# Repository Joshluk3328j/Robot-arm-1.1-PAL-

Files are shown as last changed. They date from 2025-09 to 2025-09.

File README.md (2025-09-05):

# Robot Arm v1.1 – PAL

Welcome to the second iteration of the **6 DOF Robotic Arm** project, codenamed **PAL** (Precision Articulated Limb). This version brings significant improvements over its predecessor, featuring lighter yet stronger components, enhanced torque calculations, and refined control logic. Developed during my Industrial Training at **NCAIR**, with guidance and support from **@Mac Anthony**.

🔗 **Related Links**  
- [Robot Arm v1.0](https://github.com/Joshluk3328j/robot-arm-1.0)
- [Robot Arm v1.1 PAL Repository](https://github.com/Joshluk3328j/Robot-arm-1.1-PAL-)

---

## 📂 Repository Structure

```
├── blocks/                  # Conceptual block diagrams
├── code/                    # Arduino Nano control code (servo, joystick, playback)
├── drawings/                # Technical drawings of parts
├── Gcode/                   # 3D printer G-code files
├── PRT files/               # Native CAD part files (SolidWorks/Creo)
│   ├── Base/                # Base components
│   ├── controller/          # Controller housing
│   ├── end_effector/        # Gripper/end effector parts
│   ├── Link/                # Arm linkage components
│   └── ...
├── Rendered/                # Rendered images of the design
│   ├── arm/                 # Arm renders
│   └── controller_box/      # Controller renders
├── STL files/               # 3D-printable STL models
│   ├── base/                # Base STL files
│   ├── controller_box/      # Controller housing STL files
│   ├── end_effector/        # Gripper STL files
│   └── links/               # Arm linkage STL files
└── torque_calc/             # Torque requirement calculations
```

---

## ⚙️ Features

- **6 Degrees of Freedom (DOF)**: Full range of motion for precise control.
- **Arduino Nano Control**: Powered by an Arduino Nano for reliable operation.
- **Joystick & Button Inputs**: Intuitive manual control with joysticks and buttons.
- **Motion Recording & Playback**: Store motion sequences and replay them autonomously.
- **Optimized Torque Calculations**: Ensures reliable performance under load.
- **Lightweight Design**: Uses optimized CAD parts for reduced weight and increased strength.
- **3D-Printable**: Includes STL files and G-code for easy fabrication.

---

## 🚀 Getting Started

### Hardware Requirements
- **Arduino Nano** (microcontroller)
- **6x Servo Motors** (for arm joints)
- **Joysticks** (potentiometer-based for axes control)
- **Control Buttons + Buzzer** (for user inputs and feedback)
- **3D-Printed Parts** (STL and G-code files provided in `STL files/` and `Gcode/`)

### Software Requirements
- **Arduino IDE**: For uploading control code (located in `code/`).
- **SolidWorks/Creo**: For viewing/editing CAD files (located in `PRT files/`).
- **Cura/PrusaSlicer**: For slicing STL files for 3D printing (located in `STL files/`).

### Installation
1. **Clone the Repository**:
   ```bash
   git clone https://github.com/Joshluk3328j/Robot-arm-1.1-PAL-
   ```
2. **Upload Arduino Code**:
   - Open `code/` in the Arduino IDE.
   - Connect the Arduino Nano and upload the code.
3. **3D Print Parts**:
   - Use Cura/PrusaSlicer to slice STL files in `STL files/`.
   - Print using a 3D printer or use provided G-code in `Gcode/`.
4. **Assemble Hardware**:
   - Follow technical drawings in `drawings/` for assembly.
   - Connect servo motors, joysticks, buttons, and buzzer to the Arduino Nano as per the schematics in `blocks/`.

---

## 🎮 Controls

### Joystick Controls
- **Axes**: Control **base**, **shoulder**, **elbow**, and **wrist pitch**.
- **Button Left/Right**:
  - Single press: Control **wrist roll** and **gripper**.
  - Double press: Toggle direction of wrist roll/gripper.

### Button Controls
- **Button1 (Pin 12)**:
  - **Single Press**: Save the current arm position.
  - **Double Press**: Switch between **MANUAL** and **PLAY** modes.
- **Button2 (Pin 4)**:
  - **Single Press (in PLAY mode)**: Pause or resume playback.
  - **Double Press (in MANUAL mode)**: Delete the last recorded motion.
  - **Double Press (in PLAY mode)**: Clear all saved motions.

---

## 📸 Demo

### Rendered Arm
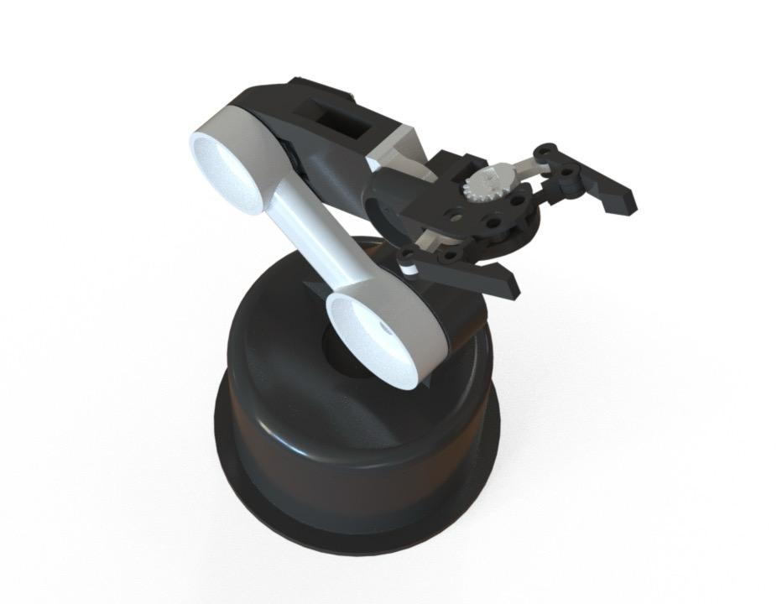
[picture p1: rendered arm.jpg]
Rendered Arm
 

### Built Arm (Real Prototype)
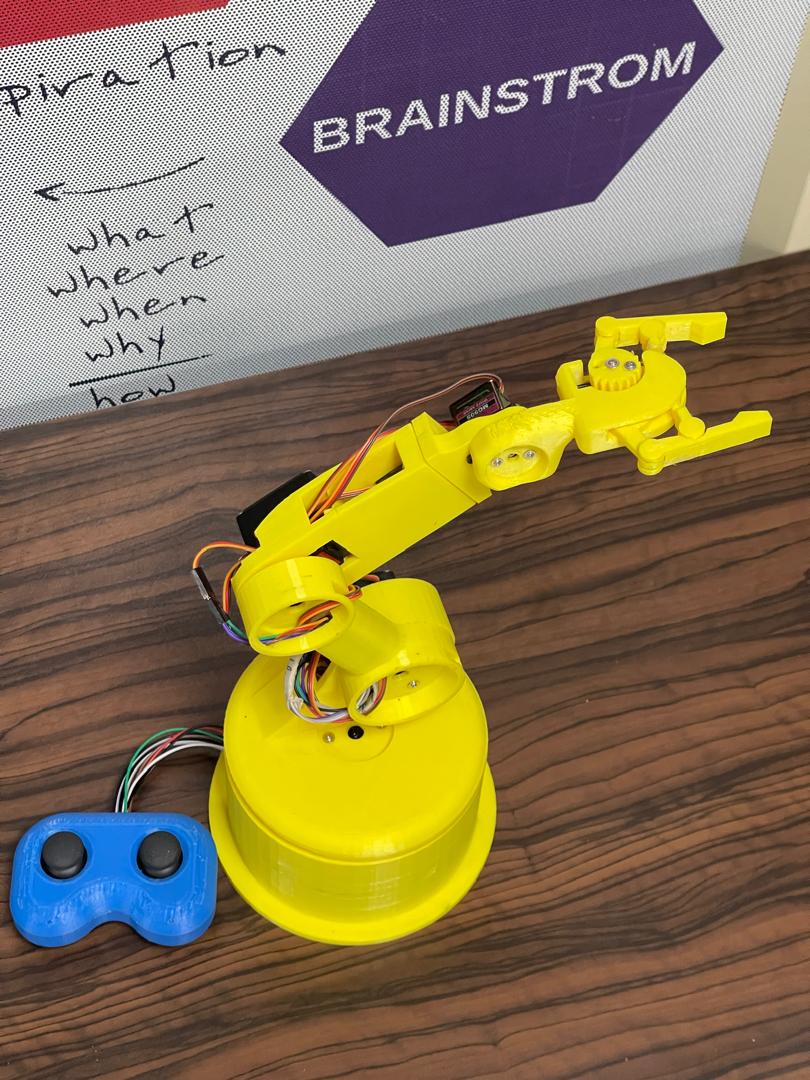
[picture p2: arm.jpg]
Built Arm


---

## 🙏 Acknowledgements

- **God**: For strength and inspiration.
- **@Mac Anthony**: For guidance and mentorship.
- **NCAIR**: For providing the opportunity and resources to develop this project.

---

## 📜 License

This project is licensed under the **MIT License**.  
Feel free to fork, modify, and enhance the project! 🚀

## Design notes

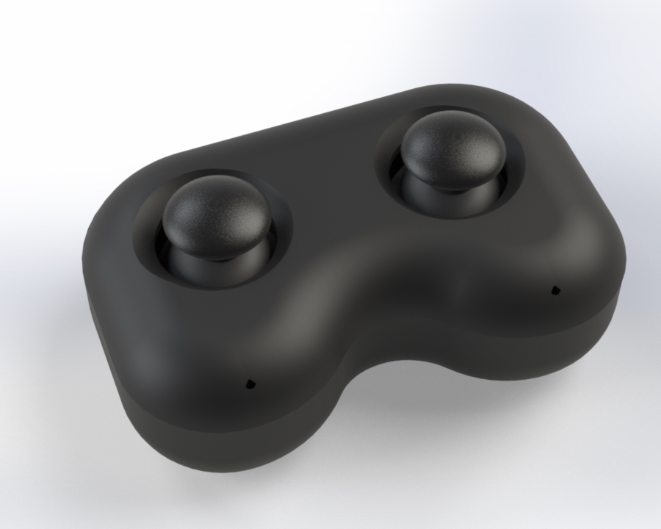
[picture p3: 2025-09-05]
Rendered/controller_box/controller_box.jpg

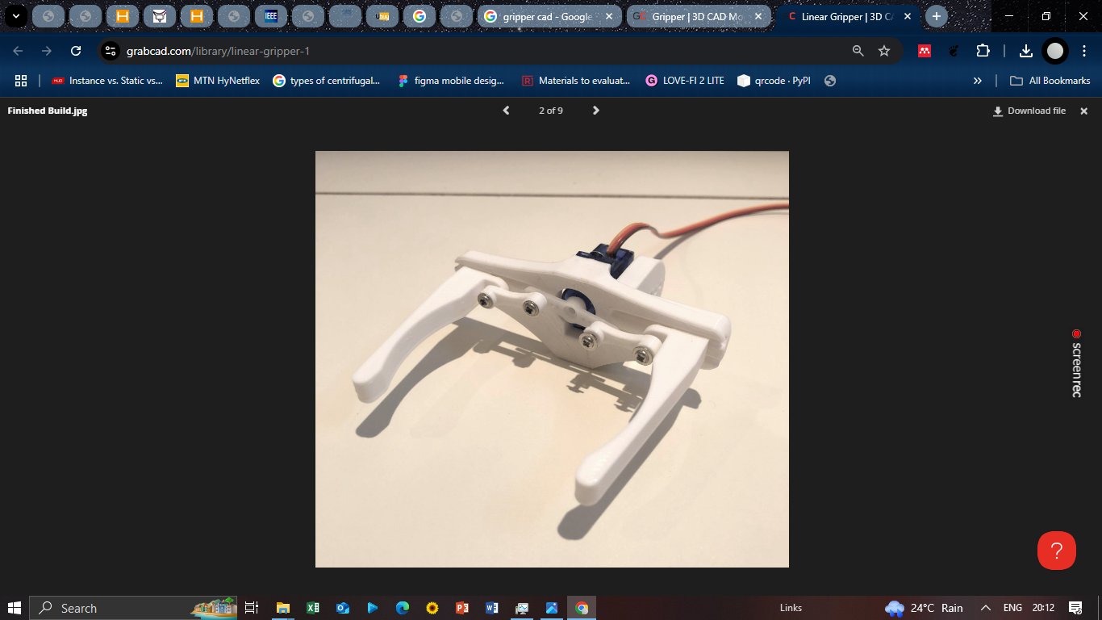
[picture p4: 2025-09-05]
PRT files/end_effector/Screenshot (245).png

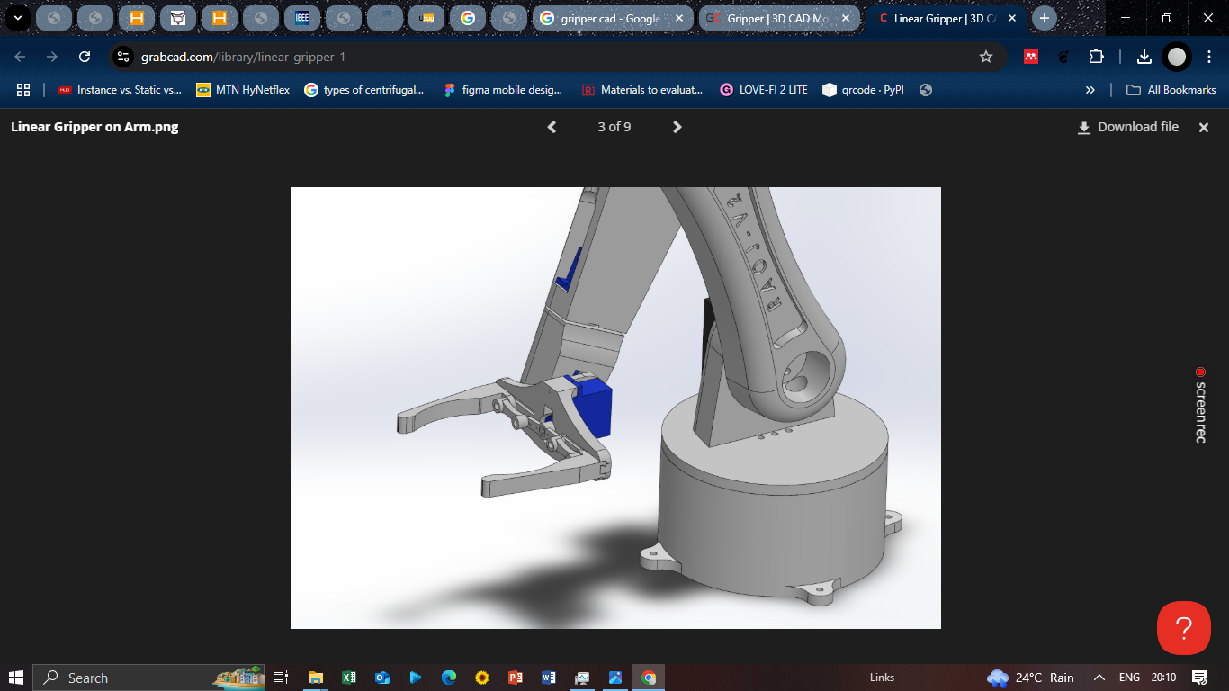
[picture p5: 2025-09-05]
PRT files/end_effector/Screenshot (244).png

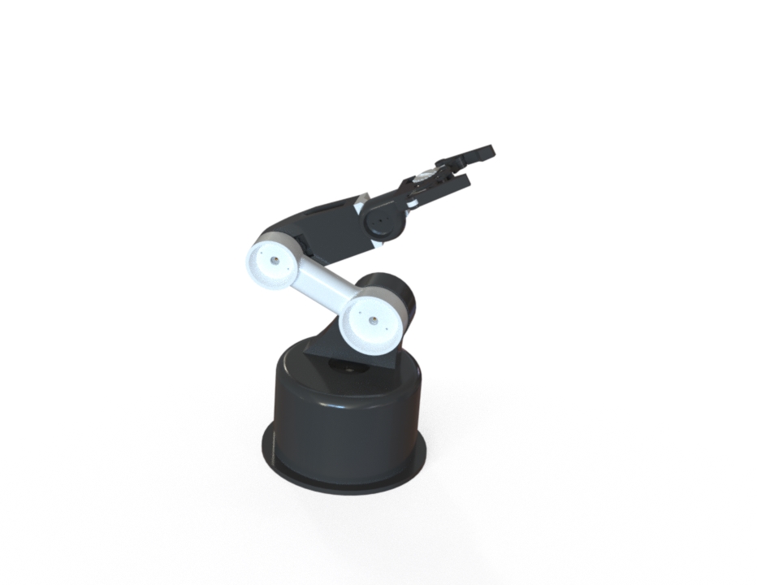
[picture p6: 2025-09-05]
Rendered/arm/arm1/arm1.jpg

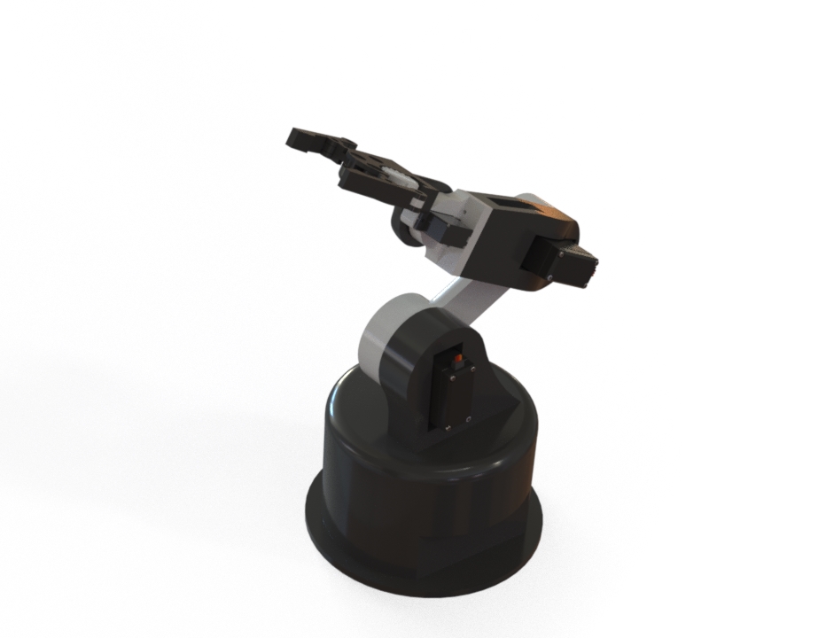
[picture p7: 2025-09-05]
Rendered/arm/arm3/arm3.jpg

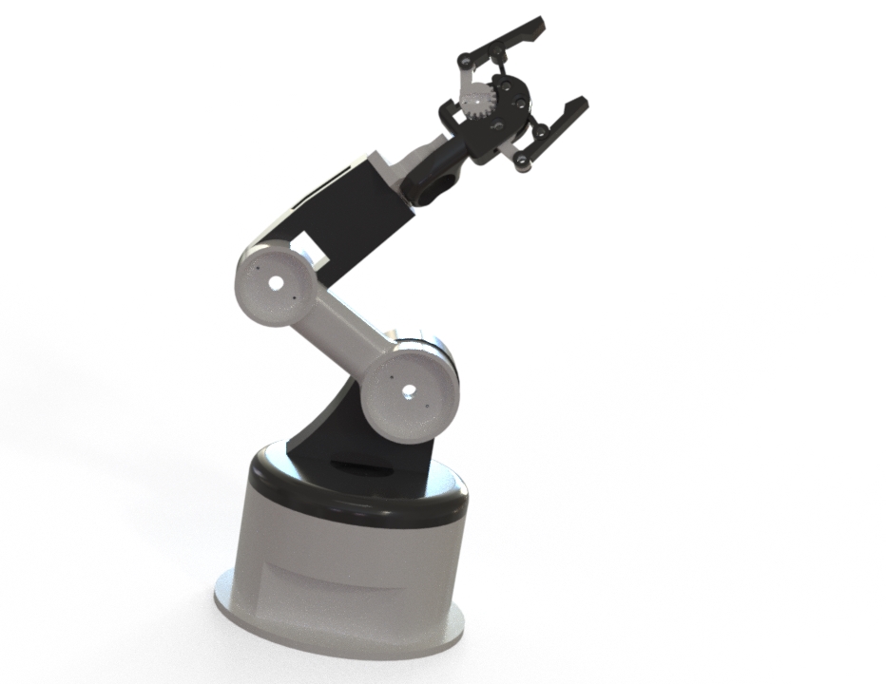
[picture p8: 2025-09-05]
Rendered/arm/arm4/arm4.jpg

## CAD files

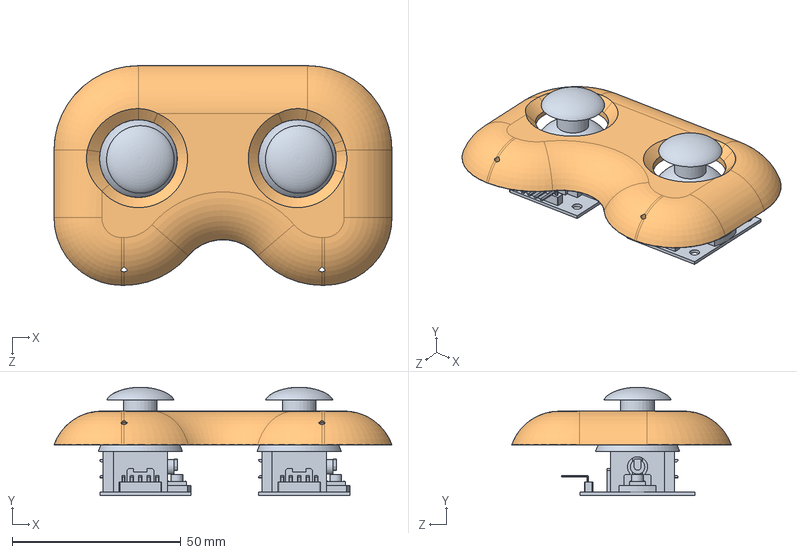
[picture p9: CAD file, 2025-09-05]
PRT files/controller/Assem1.SLDASM
100.0 x 32.0 x 65.0 mm
Controller Part2
Joystick HW504 Board x 2

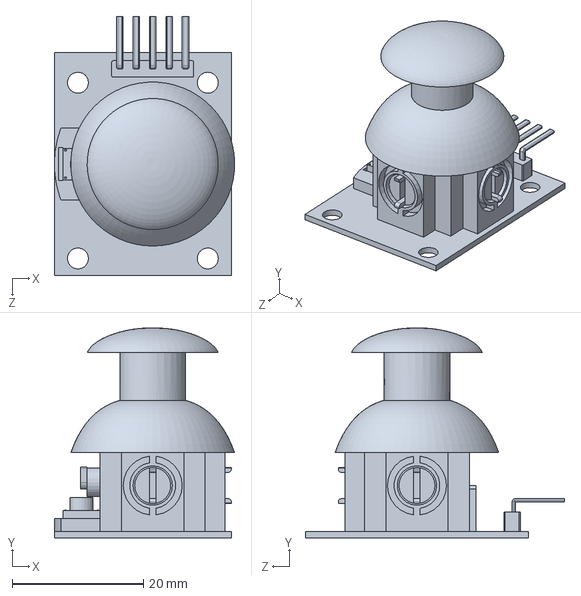
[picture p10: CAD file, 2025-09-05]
PRT files/controller/Joystick HW504 Board.SLDPRT
27.5 x 32.0 x 39.5 mm

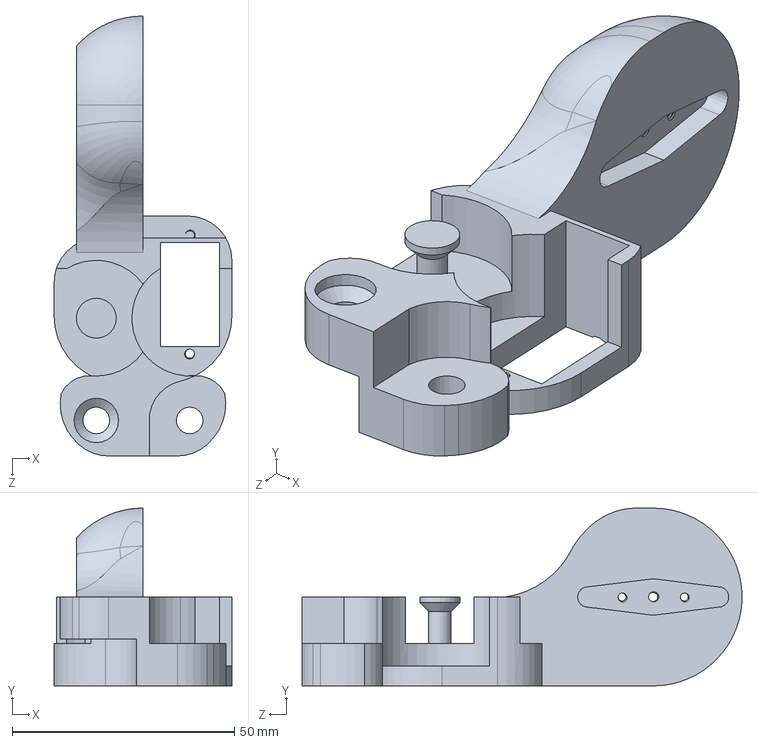
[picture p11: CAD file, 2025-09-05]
PRT files/end effector/end_effector_part1.SLDPRT
40.0 x 40.0 x 99.0 mm

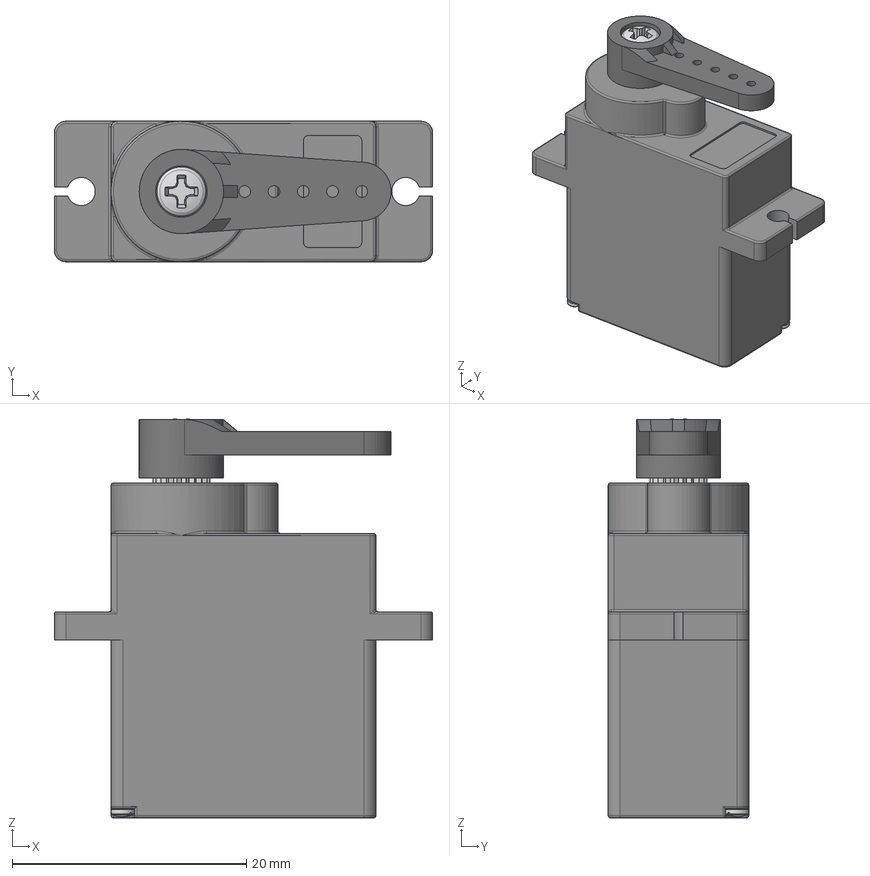
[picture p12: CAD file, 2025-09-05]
PRT files/end_effector/MG90S Micro Servo Motor.step
32.3 x 12.0 x 34.1 mm
Shaft
Horn
Screw

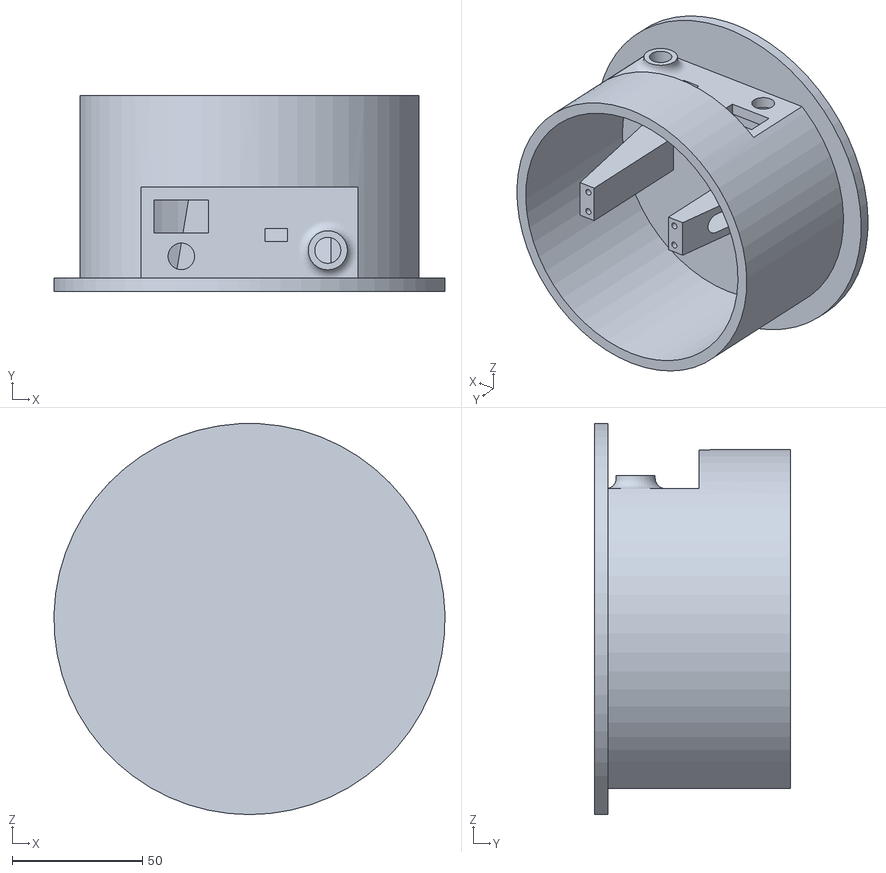
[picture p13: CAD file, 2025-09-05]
STL files/base/Base.STL
149.9 x 75.0 x 150.0

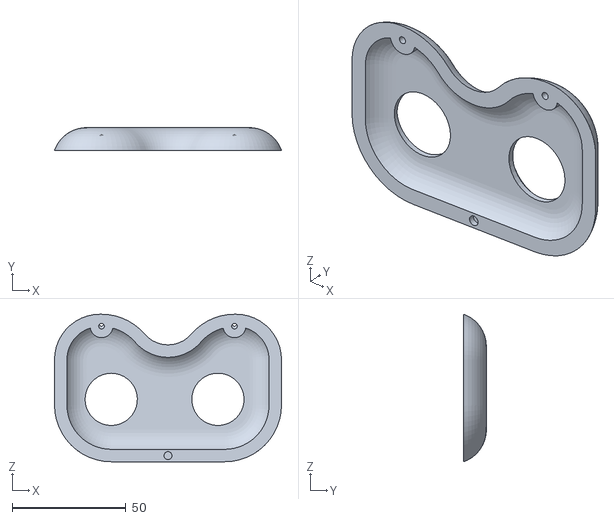
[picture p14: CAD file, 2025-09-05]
STL files/controller_box/Controller Part2.STL
100.0 x 10.00 x 65.0

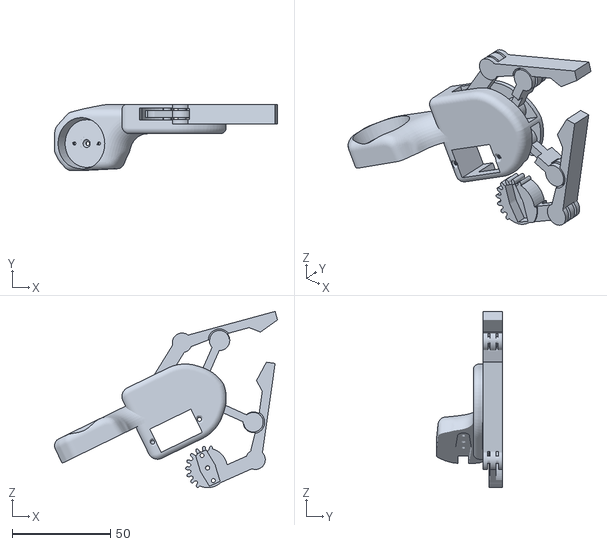
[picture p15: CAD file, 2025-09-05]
STL files/end_effector/Assem1.STL
113.7 x 33.9 x 89.9

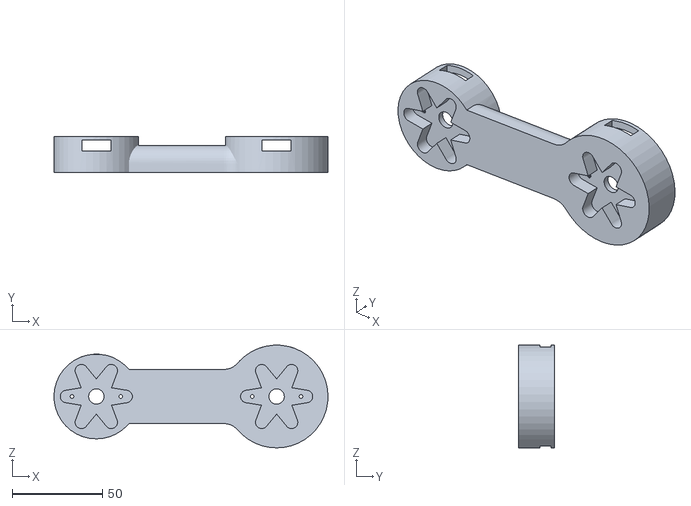
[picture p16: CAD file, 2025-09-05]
STL files/links/Link2.STL
152.0 x 20.0 x 57.0

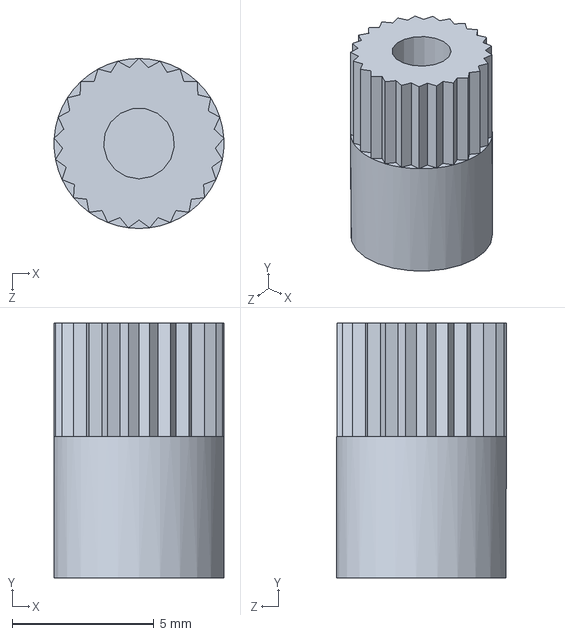
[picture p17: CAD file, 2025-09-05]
PRT files/Base/Servo MG996R Shaft.SLDPRT
5.99 x 9.00 x 6.00 mm

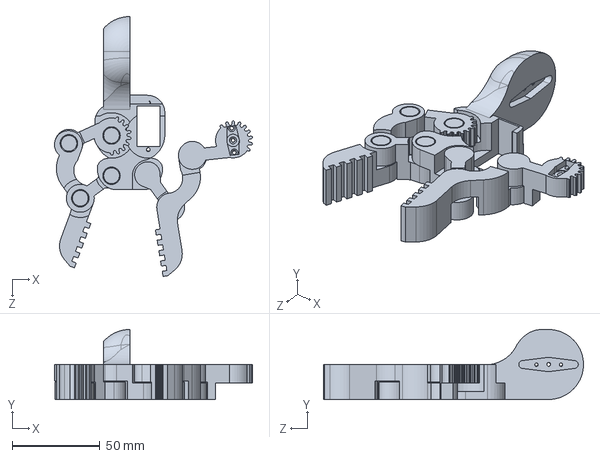
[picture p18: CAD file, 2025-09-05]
PRT files/end effector/end_effector2.SLDPRT
113.1 x 40.0 x 148.5 mm

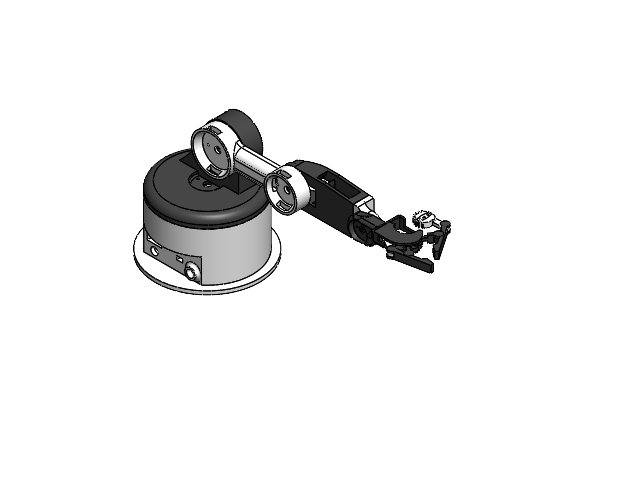
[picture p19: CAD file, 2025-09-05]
PRT files/Assembly.SLDASM
Link1
Link2
link3
link4
Base
gear
gear2
case

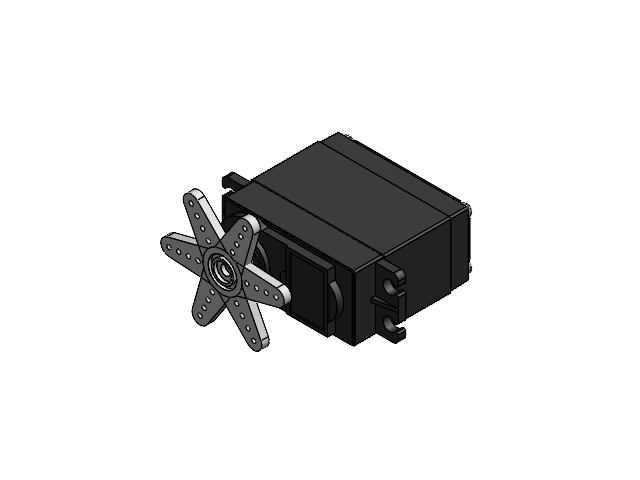
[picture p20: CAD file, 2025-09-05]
PRT files/Base/MG996R SBORKA.SLDASM
Servo MG996R
Servo MG996R Shaft
Servo MG996R arm01 x 3

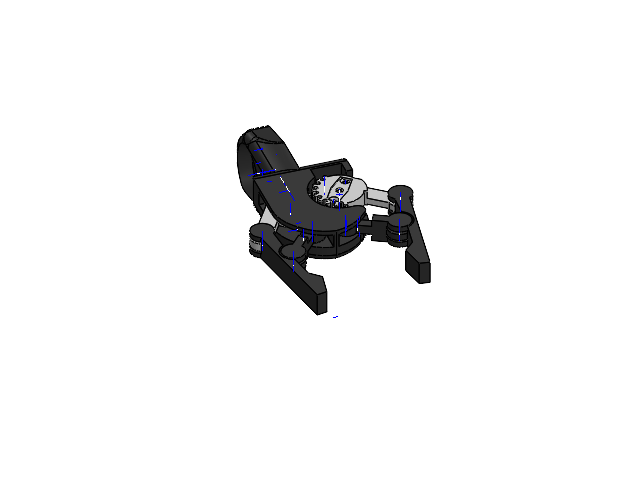
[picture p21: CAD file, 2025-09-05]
PRT files/end_effector_2/Assem1.SLDASM
gear
gear2
case

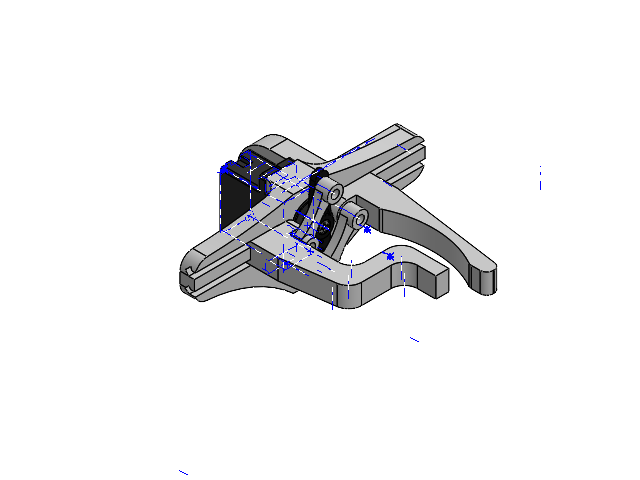
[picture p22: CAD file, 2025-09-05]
PRT files/end_effector/Linear Gripper.SLDASM
Linear Base
LGrip
Linear Link x 2
LGrip Mirror
MG90S Micro Servo Motor

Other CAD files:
PRT files/Base/base_assembly.SLDASM
PRT files/end effector/end_effector.SLDASM
PRT files/controller/Controller Part2.SLDPRT
PRT files/Base/Base.SLDPRT
PRT files/Base/Servo MG996R arm01.SLDPRT
PRT files/Base/Servo MG996R.SLDPRT
PRT files/Link/Link1.SLDPRT
PRT files/Link/Link2.SLDPRT
PRT files/Link/MG90S Micro Servo Motor.SLDPRT
PRT files/Link/l.SLDPRT
PRT files/Link/link3.SLDPRT
PRT files/Link/link4.SLDPRT
PRT files/controller/Controller Part1.SLDPRT
PRT files/end effector/Part1.SLDPRT
PRT files/end effector/end_effector.SLDPRT
PRT files/end effector/end_effector_claw.SLDPRT
PRT files/end effector/end_effector_gear.SLDPRT
PRT files/end effector/end_effector_gear2.SLDPRT
PRT files/end_effector/LGrip Mirror.SLDPRT
PRT files/end_effector/LGrip.SLDPRT
PRT files/end_effector/LGrip_2.SLDPRT
PRT files/end_effector/Linear Base.SLDPRT
PRT files/end_effector/Linear Link.SLDPRT
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

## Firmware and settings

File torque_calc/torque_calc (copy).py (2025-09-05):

# Constants
acc_d_gravity = 9.8          # Acceleration due to gravity (m/s^2)
g2kg = 1 / 1000              # Conversion from grams to kilograms
mm2m = 1 / 1000              # Conversion from millimeters to meters

def calc(
    l2_l: float, l2_mass: float,
    l3_l: float, l3_mass: float,
    l4_l: float, l4_mass: float,
    ee_l: float, ee_mass: float,
    servo2: float = 56, servo3: float = 13.4
) -> float:
    """
    Computes the total torque required at the shoulder joint due to link masses and servo weights.

    Parameters:
    - l2_l, l3_l, l4_l, ee_l: Lengths of links in mm
    - l2_mass, l3_mass, l4_mass, ee_mass: Masses of links in grams
    - servo2, servo3: Masses of servos in grams (servo2 is closer to base)

    Returns:
    - Total torque in Nm (printed)
    """

    # Masses and lengths of the links
    link_masses: list[float] = [l2_mass, l3_mass, l4_mass, ee_mass]
    link_lengths: list[float] = [l2_l, l3_l, l4_l, ee_l]

    # Compute gravitational forces (weights) in Newtons
    link_weights: dict[str, float] = {}
    for i, mass_g in enumerate(link_masses):
        link_weights[f"l{i+2}"] = (mass_g * g2kg) * acc_d_gravity  # F = m * g

    # Calculate torque contribution from each link mass
    link_torques: list[float] = []
    cumulative_distance: float = 0  # running total of distances from base

    for i, (_, weight) in enumerate(link_weights.items()):
        # Add half of the current link’s length to get to its CoG
        cumulative_distance += (link_lengths[i] / 2) * mm2m
        torque = weight * cumulative_distance
        link_torques.append(torque)

        # Add the remaining half to prepare for next link
        cumulative_distance += (link_lengths[i] / 2) * mm2m

    # Calculate torque contribution from servo masses (assuming mounted at joint ends)
    servo_torques: list[float] = []
    servo_distances_mm: list[float] = [
        link_lengths[0] + link_lengths[1] / 2,
        link_lengths[0] + link_lengths[1],
        link_lengths[0] + link_lengths[1] + link_lengths[2],
        link_lengths[0] + link_lengths[1] + link_lengths[2] + link_lengths[3],
    ]
    servo_distances_m: list[float] = [d * mm2m for d in servo_distances_mm]

    # Convert servo masses to forces (N)
    servo_weights: list[float] = [
        servo2 * g2kg * acc_d_gravity,
        servo3 * g2kg * acc_d_gravity,
        servo3 * g2kg * acc_d_gravity,
        servo3 * g2kg * acc_d_gravity,
    ]

    # Calculate torque from each servo
    for weight, distance in zip(servo_weights, servo_distances_m):
        torque = weight * distance
        servo_torques.append(torque)

    # Total torque from links and servos
    total_torque: float = sum(link_torques) + sum(servo_torques)
    print(f"Total torque from links and servos: {total_torque:.3f} Nm")
    return total_torque, sum(link_lengths)


def torque_mass_length(mass_g: float, length_mm: float) -> None:
    """
    Calculates torque produced by a point mass at a given distance.

    Parameters:
    - mass_g: Mass in grams
    - length_mm: Lever arm distance in mm
    """
    weight = mass_g * g2kg * acc_d_gravity
    distance_m = length_mm * mm2m
    torque = weight * distance_m
    print(f"Torque from {mass_g:.2f}g ({weight:.2f}N) at {length_mm}mm = {torque:.3f} Nm")


def servo_mass_distance(servo_rating_kg: float, distance_mm: float, percent: float = 100) -> None:
    """
    Estimates the maximum mass a servo can lift at a given distance, using a percentage of its max torque.

    Parameters:
    - servo_rating_kg: Torque rating in kg·cm
    - distance_mm: Lever arm distance in mm
    - percent: Percent of servo torque to use (e.g., 70%)
    """
    distance_cm = distance_mm / 10
    usable_torque_kgcm = servo_rating_kg * (percent / 100)
    usable_torque_Nm = (10 * usable_torque_kgcm) * acc_d_gravity * mm2m  # Convert kg·cm to Nm

    max_mass_kg = usable_torque_kgcm / distance_cm
    max_force_N = max_mass_kg * acc_d_gravity

    print(f"Using {percent}% of a {servo_rating_kg} kg·cm servo's torque:")
    print(f"→ Usable torque: {usable_torque_kgcm:.2f} kg·cm ≈ {usable_torque_Nm:.3f} Nm")
    print(f"→ Max load at {distance_cm:.1f} cm: {max_mass_kg:.3f} kg ({max_force_N:.2f} N)")


# Calculate total torque from full arm setup
torque, full_extension = calc(
    l2_l=100, l2_mass=50,
    l3_l=84.991, l3_mass=50,
    l4_l=41.647,  l4_mass=50,
    ee_l=119.535, ee_mass=50
)

# Check usable Torque full length using 70% torque
servo_mass_distance(11, full_extension, 70)

# # Get torque from 350g at the full length of all links
# torque_mass_length(350, full_extension)

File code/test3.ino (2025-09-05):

// ---------------- ROBOT ARM CONTROL ----------------
#include <Servo.h>

#define NUM_AXES 4
int joyPins[NUM_AXES] = {A0, A1, A2, A3};  // Joystick axes
Servo servos[6];                            // 6 DOF robot

// Buttons
int buttonLeft   = 7;   // Wrist roll
int buttonRight  = 8;   // Gripper
int buttonRecord = 12;  // Button1
int buttonPlay   = 4;   // Button2

// Buzzer
int buzzerPin = 2;

// Servo positions
int servoPos[6] = {90, 90, 90, 90, 90, 90};
int stepSize = 2;      // Manual move step size
int deadzone = 100;

// Button timing
unsigned long lastPressLeft  = 0;
unsigned long lastPressRight = 0;
unsigned long lastPressRec   = 0;
unsigned long lastPressPlay  = 0;
unsigned long doublePressWindow = 400; // ms
bool leftReverse  = false;
bool rightReverse = false;

// Step timing (manual control)
unsigned long lastStepTime = 0;
unsigned long stepInterval = 50; // ms between increments

// Playback timing
unsigned long lastPlayTime = 0;
unsigned long playInterval = 1000; // ms between motions

// Mode and motion memory
enum Mode { MANUAL, PLAY };
Mode currentMode = MANUAL;
bool isPlaying = false;

const int MAX_MOTIONS = 50;
int motions[MAX_MOTIONS][6]; // store up to 50 frames
int motionCount = 0;
int playIndex = 0;

// Playback helpers
int targetPos[6];
bool moving = false;

// ---------------- BUZZER HELPERS ----------------
void beep(int freq, int dur) {
  tone(buzzerPin, freq, dur);
  delay(dur);
  noTone(buzzerPin);
}
void longBuzz() { beep(600, 600); }

// ---------------- MOTION MEMORY ----------------
void saveMotion() {
  if (motionCount < MAX_MOTIONS) {
    for (int i = 0; i < 6; i++) {
      motions[motionCount][i] = servoPos[i];
    }
    motionCount++;
    beep(2000, 100);
    Serial.print("Saved motion #");
    Serial.println(motionCount);
  } else {
    beep(400, 200); // error beep if full
    Serial.println("Memory full!");
  }
}

void deleteLastMotion() {
  if (motionCount > 0) {
    motionCount--;
    beep(1200, 150);
    Serial.print("Deleted last motion. Remaining: ");
    Serial.println(motionCount);
  } else {
    beep(400, 200);
    Serial.println("No motions to delete!");
  }
}

void clearAllMotions() {
  motionCount = 0;
  beep(800, 300);
  Serial.println("All motions cleared!");
}

void setup() {
  Serial.begin(9600);

  pinMode(buttonLeft, INPUT_PULLUP);
  pinMode(buttonRight, INPUT_PULLUP);
  pinMode(buttonRecord, INPUT_PULLUP);
  pinMode(buttonPlay, INPUT_PULLUP);

  servos[0].attach(3);   // Base
  servos[1].attach(5);   // Shoulder
  servos[2].attach(6);   // Elbow
  servos[3].attach(9);   // Wrist pitch
  servos[4].attach(10);  // Wrist roll
  servos[5].attach(11);  // Gripper

  pinMode(buzzerPin, OUTPUT);

  Serial.println("=== ROBOT ARM CONTROL STARTED ===");
}

void loop() {
  unsigned long now = millis();

  bool leftPressed   = (digitalRead(buttonLeft) == LOW);
  bool rightPressed  = (digitalRead(buttonRight) == LOW);
  bool recPressed    = (digitalRead(buttonRecord) == LOW);
  bool playPressed   = (digitalRead(buttonPlay) == LOW);

  // ---------------- MANUAL MODE CONTROL ----------------
  if (currentMode == MANUAL && now - lastStepTime >= stepInterval) {
    lastStepTime = now;

    // Joysticks 0–3
    for (int i = 0; i < NUM_AXES; i++) {
      int val = analogRead(joyPins[i]);
      if (val < (512 - deadzone)) {
        servoPos[i] = constrain(servoPos[i] - stepSize, 0, 180);
      } else if (val > (512 + deadzone)) {
        servoPos[i] = constrain(servoPos[i] + stepSize, 0, 180);
      }
      servos[i].write(servoPos[i]);
    }

    // Wrist roll (buttonLeft)
    static bool leftPrev = false;
    if (leftPressed && !leftPrev) {
      if (now - lastPressLeft < doublePressWindow) {
        leftReverse = !leftReverse;
        beep(1200, 80);
      } else {
        beep(1000, 50);
      }
      lastPressLeft = now;
    }
    leftPrev = leftPressed;

    if (leftPressed) {
      servoPos[4] = constrain(servoPos[4] + (leftReverse ? -stepSize : stepSize), 0, 180);
      servos[4].write(servoPos[4]);
    }

    // Gripper (buttonRight)
    static bool rightPrev = false;
    if (rightPressed && !rightPrev) {
      if (now - lastPressRight < doublePressWindow) {
        rightReverse = !rightReverse;
        beep(1700, 80);
      } else {
        beep(1500, 50);
      }
      lastPressRight = now;
    }
    rightPrev = rightPressed;

    if (rightPressed) {
      servoPos[5] = constrain(servoPos[5] + (rightReverse ? -stepSize : stepSize), 0, 180);
      servos[5].write(servoPos[5]);
    }
  }

  // ---------------- PLAYBACK MODE ----------------
  if (currentMode == PLAY && isPlaying && motionCount > 0) {
    if (!moving) {
      // Load next target frame
      for (int i = 0; i < 6; i++) {
        targetPos[i] = motions[playIndex][i];
      }
      Serial.print("Playing motion #");
      Serial.println(playIndex + 1);
      beep(1000, 30); // short beep between frames
      moving = true;
    }

    // Smooth step towards target
    bool reached = true;
    for (int i = 0; i < 6; i++) {
      if (servoPos[i] < targetPos[i]) {
        servoPos[i]++;
        reached = false;
      } else if (servoPos[i] > targetPos[i]) {
        servoPos[i]--;
        reached = false;
      }
      servos[i].write(servoPos[i]);
    }

    // If all joints reached target, wait interval then go to next frame
    if (reached && millis() - lastPlayTime >= playInterval) {
      lastPlayTime = millis();
      playIndex++;
      if (playIndex >= motionCount) playIndex = 0; // loop playback
      moving = false;
    }
  }

  // ---------------- BUTTON1: SAVE / MODE ----------------
  static bool recPrev = false;
  if (recPressed && !recPrev) {
    if (now - lastPressRec < doublePressWindow) {
      // Double press -> toggle mode
      currentMode = (currentMode == MANUAL) ? PLAY : MANUAL;
      isPlaying = false;
      playIndex = 0;
      moving = false;
      longBuzz();
      Serial.print(">>> Mode changed to: ");
      Serial.println((currentMode == MANUAL) ? "MANUAL" : "PLAY");
    } else {
      // Single press -> save motion
      saveMotion();
    }
    lastPressRec = now;
  }
  recPrev = recPressed;

  // ---------------- BUTTON2: PLAY / DELETE ----------------
  static bool playPrev = false;
  if (playPressed && !playPrev) {
    if (now - lastPressPlay < doublePressWindow) {
      if (currentMode == MANUAL) {
        deleteLastMotion();
      } else {
        clearAllMotions();
      }
    } else {
      if (currentMode == PLAY) {
        isPlaying = !isPlaying;
        beep(isPlaying ? 2200 : 800, 150);
        Serial.println(isPlaying ? ">>> PLAYING" : ">>> PAUSED");
      }
    }
    lastPressPlay = now;
  }
  playPrev = playPressed;
}
